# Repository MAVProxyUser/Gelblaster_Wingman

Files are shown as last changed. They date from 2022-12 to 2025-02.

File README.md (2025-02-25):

# Gelblaster Wingman Robotic Sentry Turret

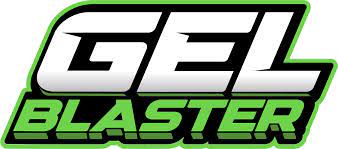
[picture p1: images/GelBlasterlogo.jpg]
Gelblasters (https://gelblaster.com)


Direct link to Bambu Labs printer files<br>
https://makerworld.com/en/models/787554#profileId-725499<br>
https://makerworld.com/en/models/787567#profileId-725512<br>

If you are interested in building & programming your own "Wingman" turret stop by:<br>
https://join.slack.com/t/robotdogs/shared_invite/zt-24ep8mqn4-1p42Aq7owRv9klLI~3C5Pw and join #gelblasters 

* [Gelblaster Wingman Robotic Sentry Turret](#gelblaster-wingman-robotic-sentry-turret)
   * [Synopsis](#synopsis)
   * [December 2024 - First Outdoor Test](#december-2024---first-outdoor-test)
   * [Introduction](#introduction)
   * [Licensing](#licensing)
   * [Build Steps](#build-steps)
      * [Required parts](#required-parts)
      * [Printing](#printing)
   * [Making a sentry gun](#making-a-sentry-gun)
      * [Required plumbing](#required-plumbing)
      * [Transplant of GelBlaster XL electronics](#transplant-of-gelblaster-xl-electronics)
      * [More 3d printing](#more-3d-printing)
      * [Recommended additional parts](#recommended-additional-parts)
         * [Motion Control](#motion-control)
         * [Computing](#computing)
         * [Power System](#power-system)

## Synopsis 

Ever since we saw James Cameron's "Aliens" in 1986, and Frank Marshall's "Congo" in 1995 we knew we needed to own an automated sentry turret at some point in our lifetime. It wasn't clear we'd eventually be sharing the design to one for others to use, but here we sit, doing exactly that. 

"Wingman" is a  licensed Open Source "GelBlaster" turret for ["general-purpose robots"](https://www.bostondynamics.com/open-letter-opposing-weaponization-general-purpose-robots). "Wingman" is designed with gamification of non-lethal adversarial Gelblaster sparring matches in mind. It makes robot assisted marksmanship a key compnent of playtime, are you ready to fight your robot overlords? No!? Well, you better get to training sooner than later!

liquor pour (https://www.youtube.com/watch?v=IS2PtmM9mwU) 

## December 2024 - First Outdoor Test
Latest Status Dec 2024 (https://youtube.com/shorts/UjThLahqY9g)<br>

## Current Tracking Response
Current Tracking Response (https://youtube.com/shorts/NoIiMvJtIzc?si=dIlFipVr6tI9Dh-7)<br>

## Introduction

[Gelblaster](https://gelblaster.com) XL "Wingman" is a robotic turret, that shoots gel balls aka Gellets(tm) at targets as selected by AI logic. The Gelblaster based "Wingman turret SDK" was inspired by U.S. Army [TARDEC](https://asc.army.mil/web/news-alt-jfm18-wingman-is-first-step-toward-weaponized-robotics/) - Tank-automotive and Armaments Command, [Open Robotics](https://www.openrobotics.org) [ROS-M](https://rosmilitary.org/faq/) military fork of Robot Operation System from GVSC - Combat Capabilities Development Command Ground Vehicle Systems Center, and their ["Wingman Robotic Gunner"](https://apps.dtic.mil/sti/pdfs/AD1069401.pdf) platform. Functionality of this project seeks to mimic concepts found in the [RTK](https://vimeo.com/593277076?) - Robotic Technology Kernel program. 

A gamified version of the "Wingman" concept known as [BloodHounds](https://github.com/MAVProxyUser/BloodHounds) is being designed by Kevin Finisterre for use with Quadruped robot dogs. This project is being tested, & developed with assistence from John Cherbini & the Gelblaster design team, as a means to visualize the "game". 

The design concept was pitched to the GelBlaster team, and the initial ideation phase reulted in the following proof of concept work. Thanks again to [GlytchTech](https://twitter.com/GlytchTech) for the very early prototypes, pre Gelblaster pitch.<br> 
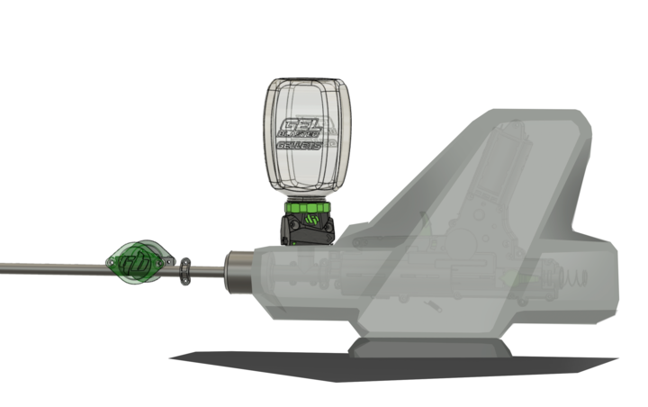
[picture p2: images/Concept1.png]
Concept1

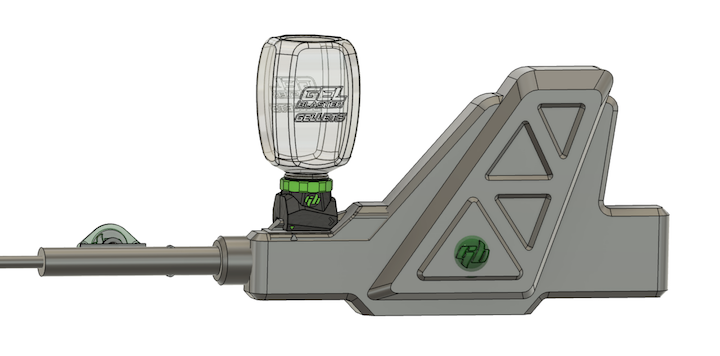
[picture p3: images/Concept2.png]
Concept2


The barrel seemed a bit vulnerable so we asked for a shroud.<br> 
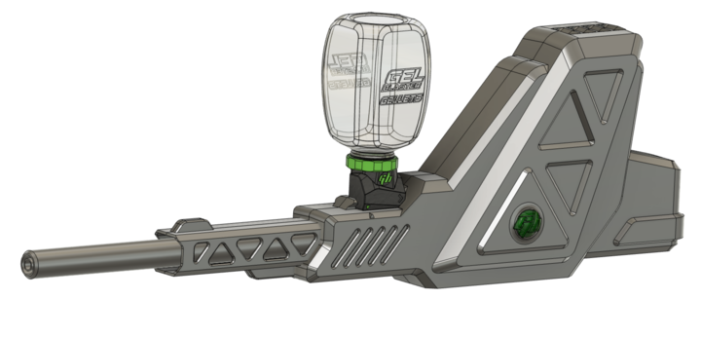
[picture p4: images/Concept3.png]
Concept3

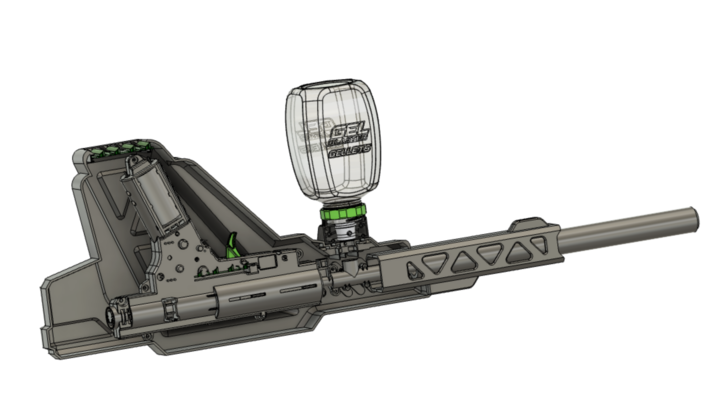
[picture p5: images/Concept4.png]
Concept4


We also needed a mounting system, pic rail seemed reasonable.<br> 
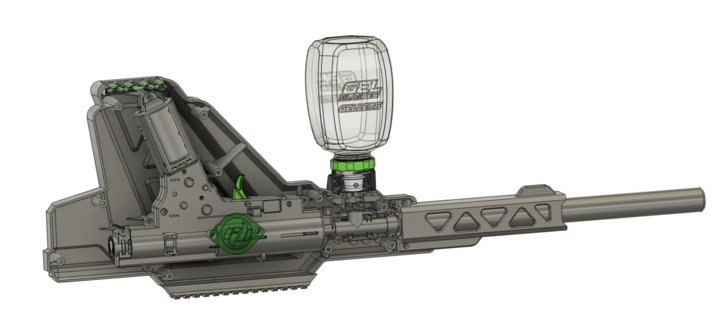
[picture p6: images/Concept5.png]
Concept5

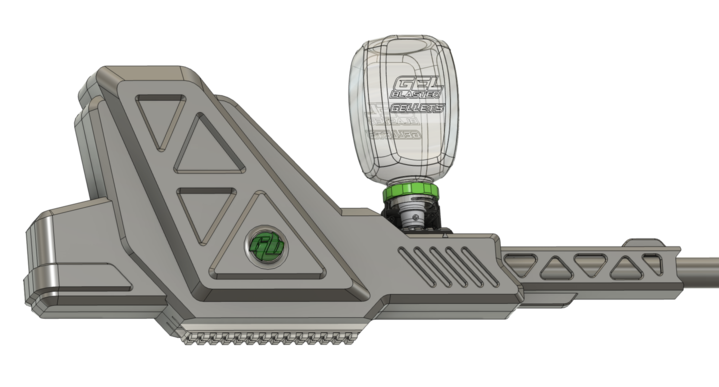
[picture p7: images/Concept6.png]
Concept6


Considerations over printability came next... and now we have something we can share. Mind you we still don't use the shroud, and we're testing sawed off barel designs. In otherwords, don't mind our mess while we are under construction.

## Licensing 

Creative Commons + Attribution-NonCommercial-ShareAlike licensing ( 
CC BY-NC-SA ) applies to the 3D files shared along side this text. This license lets others remix, adapt, and build upon your work non-commercially, as long as they credit you and license their new creations under the identical terms.

https://creativecommons.org/licenses/by-nc-sa/4.0/<br>
https://creativecommons.org/licenses/by-nc-sa/4.0/legalcode<br>

Under the following terms:

Attribution — You must give appropriate credit, provide a link to the license, and indicate if changes were made. You may do so in any reasonable manner, but not in any way that suggests the licensor endorses you or your use.

NonCommercial — You may not use the material for commercial purposes.

ShareAlike — If you remix, transform, or build upon the material, you must distribute your contributions under the same license as the original.

No additional restrictions — You may not apply legal terms or technological measures that legally restrict others from doing anything the license permits.

## Build Steps

### Required parts

[GelBlaster Surge XL](https://gelblaster.com/products/surge-xl)
or
[GelBlaster Starfire XL](https://gelblaster.com/products/starfire-xl). Either blaster can be purchased from [Walmart](https://www.walmart.com/ip/Gel-Blaster-Surge-XL-Day-N-Nite-Gel-Bead-Blaster-with-Glow-in-the-Dark-Starfire-Activator-5k-Starfire-Gellets-10k-Green-Gellets/1283028596), and [Target](https://www.target.com/p/gel-blaster-starfire-xl-glow-in-the-dark-gellet-blaster/-/A-86669382) respectively. 

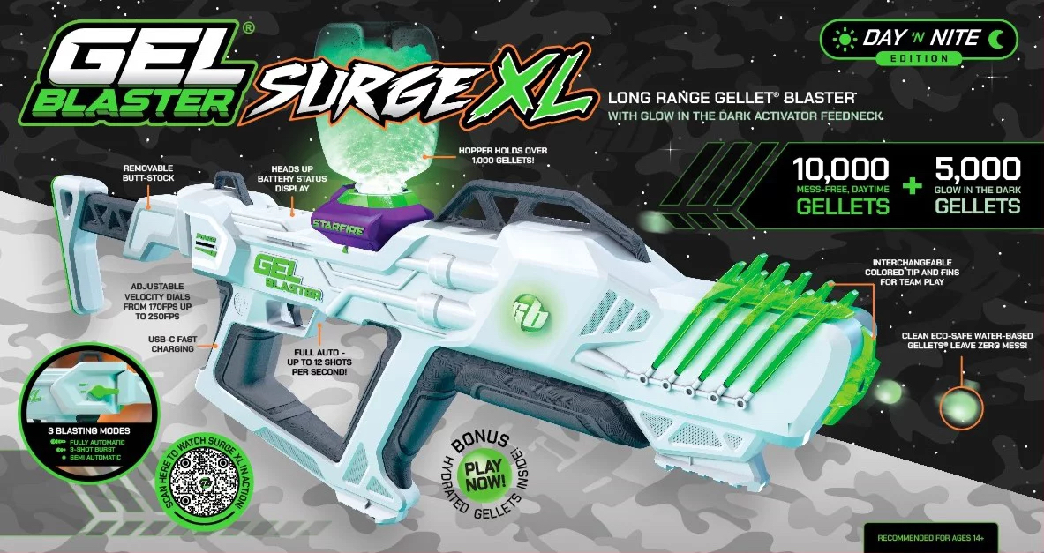
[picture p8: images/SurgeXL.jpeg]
SurgeXL

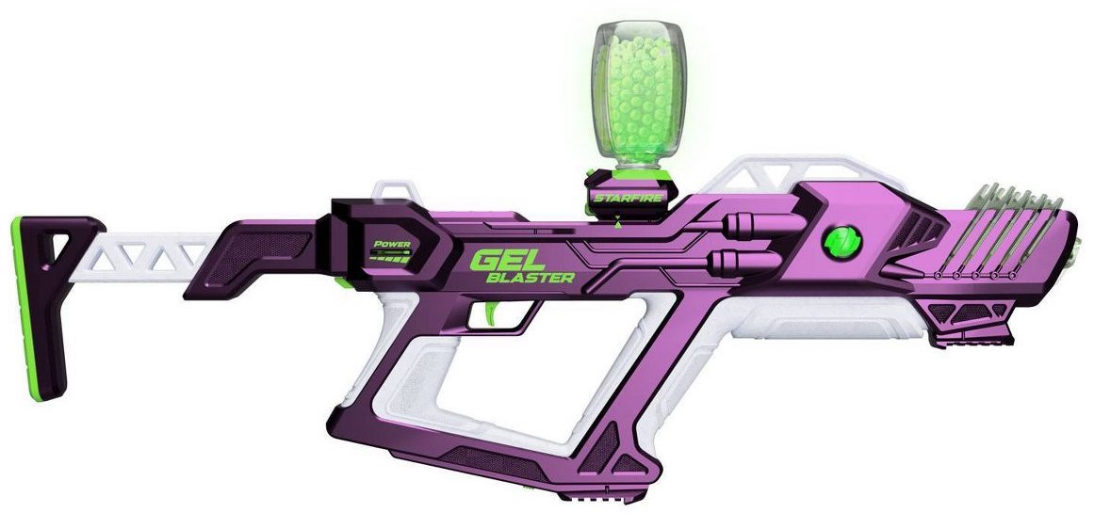
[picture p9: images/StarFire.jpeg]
StarFire XL


### Printing
The Wingman turret shell can be printed using the following pre-configured Bambu Lab build plates:

1. [Wingman GelBlaster Turret Case](https://makerworld.com/en/models/787567#profileId-725512)
2. [Wingman Turret Base](https://makerworld.com/en/models/787554#profileId-725499)

These build plates are optimized for the Bambu Lab A1 printer, but can be adapted for other printers. The complete print will take approximately 50 hours (6 hours for front pieces, 20 hours for each rear piece).

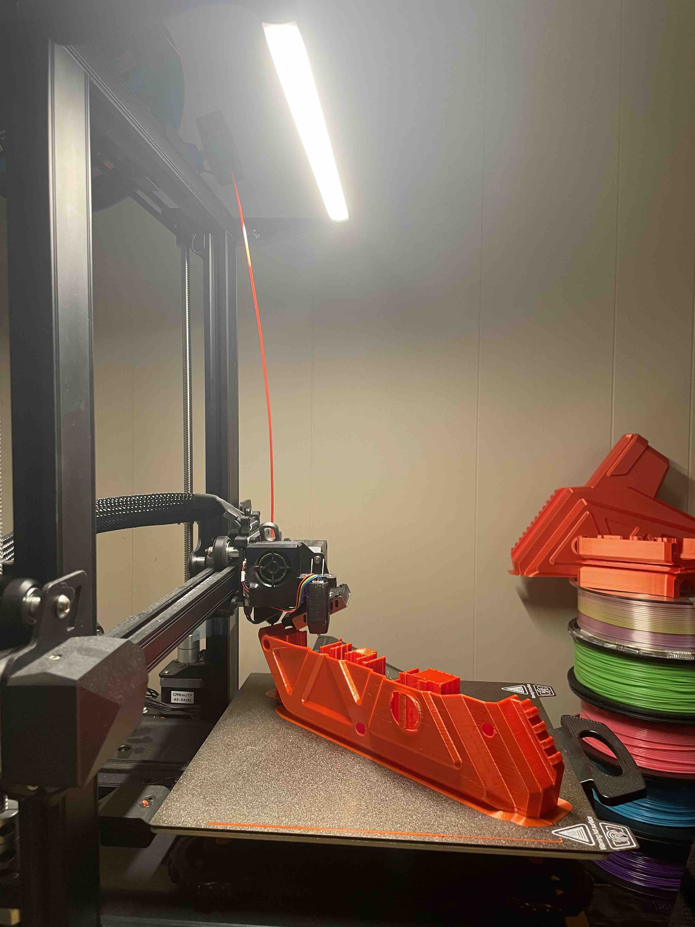
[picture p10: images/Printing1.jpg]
Printing1


After printing, you'll need to:
1. Remove support structures
2. Clean up the prints
3. Use Gorilla Glue (gel recommended) to join the shell pieces

For those wanting individual STL files:
[CC_BYNCSA_STL_Files directory](https://github.com/MAVProxyUser/Gelblaster_Wingman/)

## Making a sentry gun

### Required plumbing
First remove all the supporting screws in the GelBlaster XL shell, then remove the cosmetic shroud & barrel tip. Once the shell is open, remove the batery. <br>
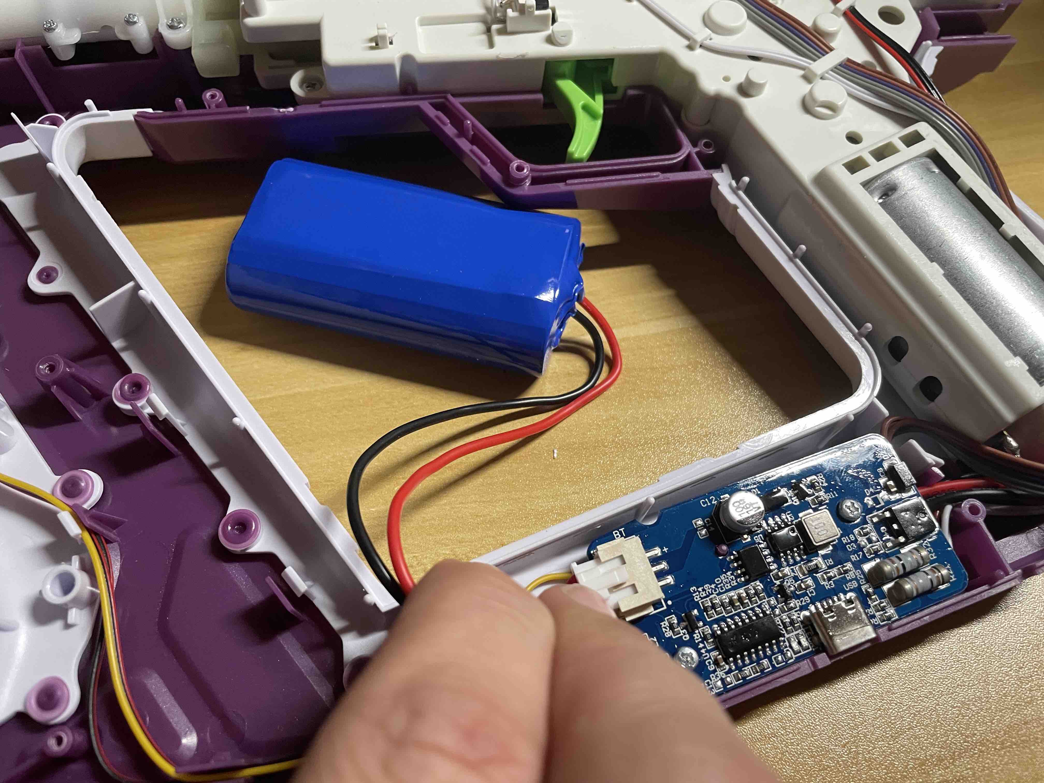
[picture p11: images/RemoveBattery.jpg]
RemoveBattery

Remove the screws and prepare to remove the gearbox.<br> 
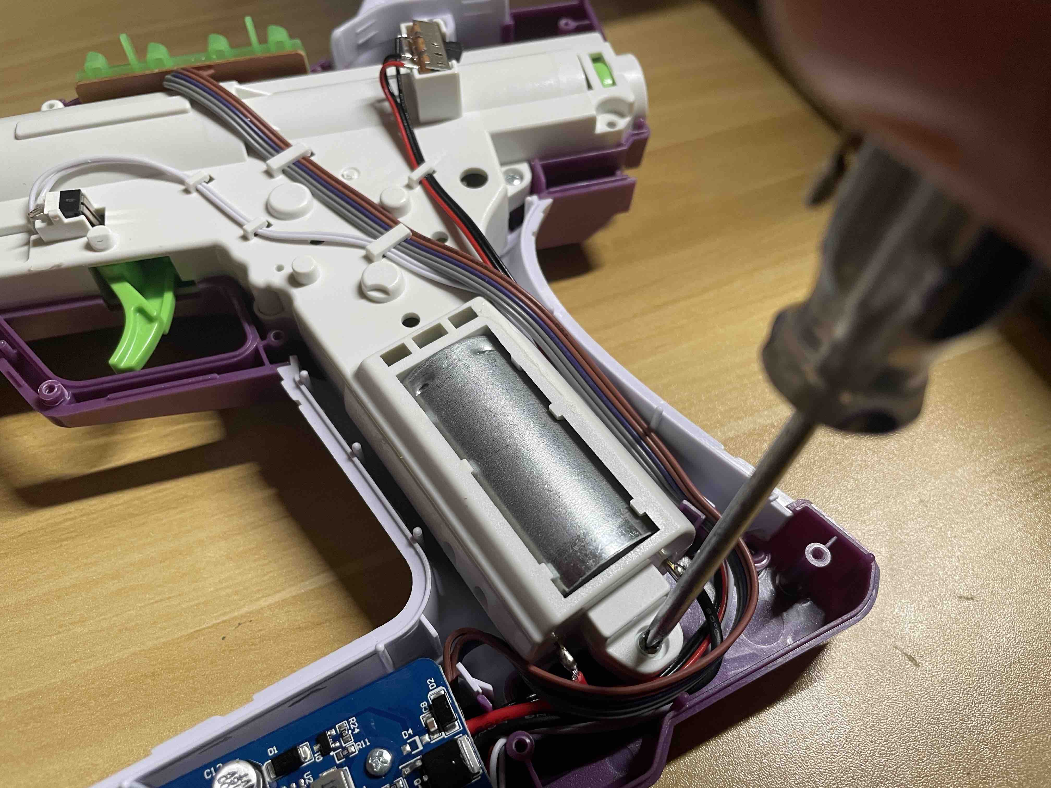
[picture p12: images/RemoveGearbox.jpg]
RemoveGearbox

Next remove the shim for the ammo hopper.<br> 
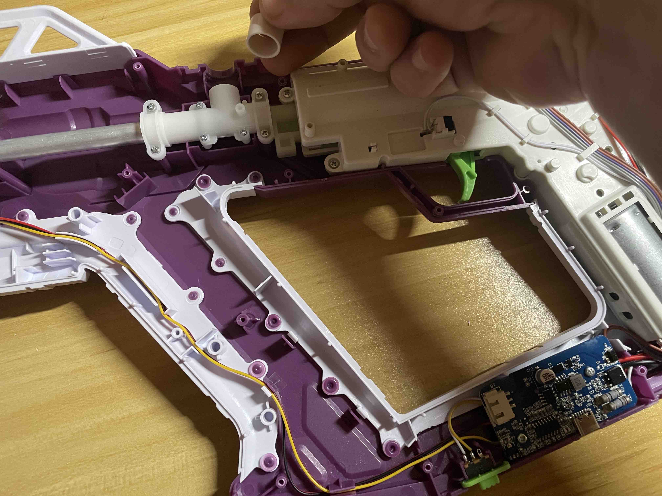
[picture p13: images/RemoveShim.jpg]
RemoveShim

Then remove the LED array, and associated cables. Do NOT disconnect them from the main PCB.<br> 
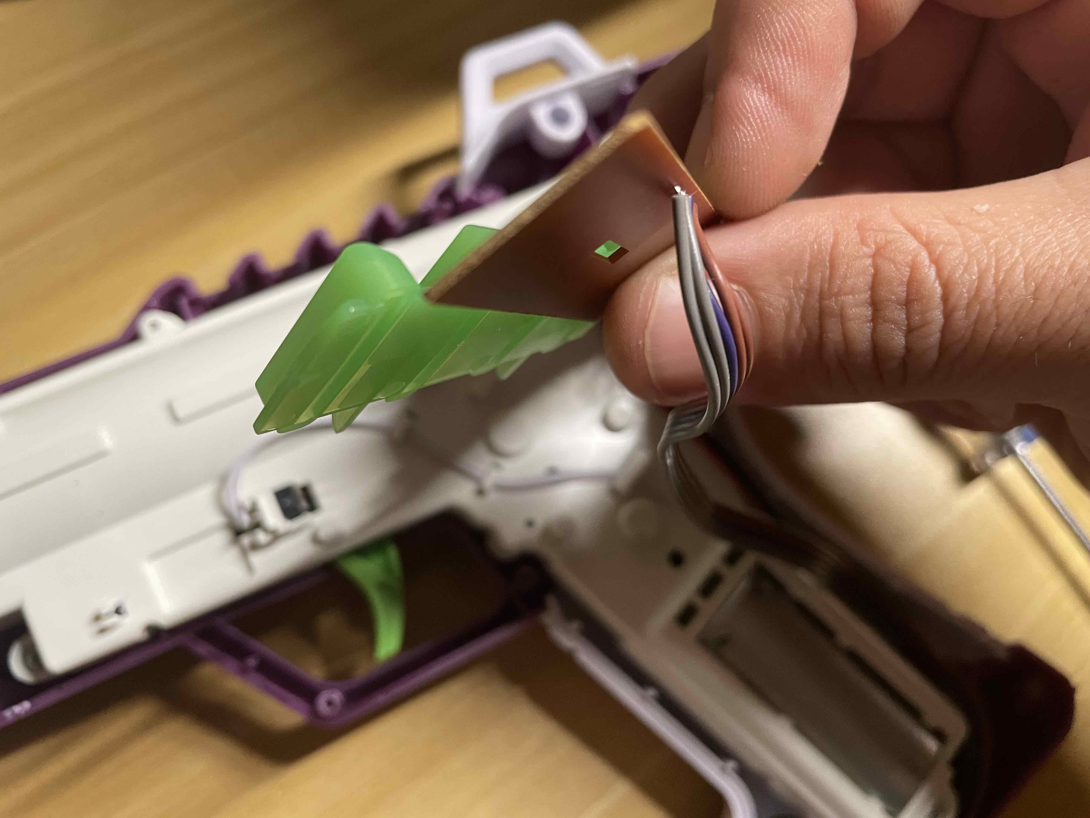
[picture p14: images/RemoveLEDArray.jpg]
RemoveLEDArray

Do the same with the other switches, and wires.<br> 
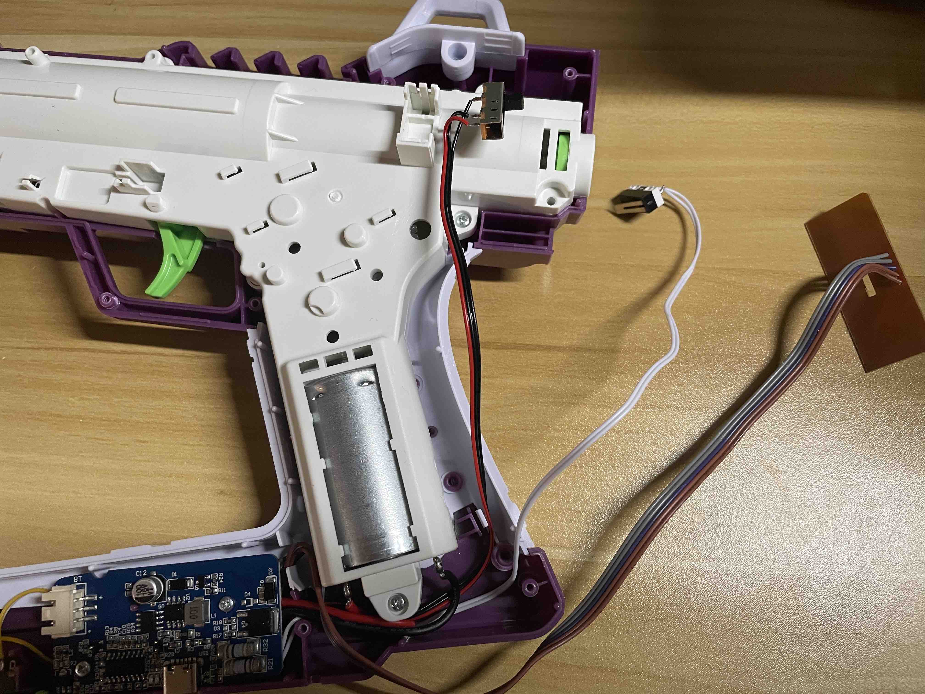
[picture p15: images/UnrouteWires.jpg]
UnrouteWires

Remove the screws holding down the PCB, and the barrel in place.<br> 
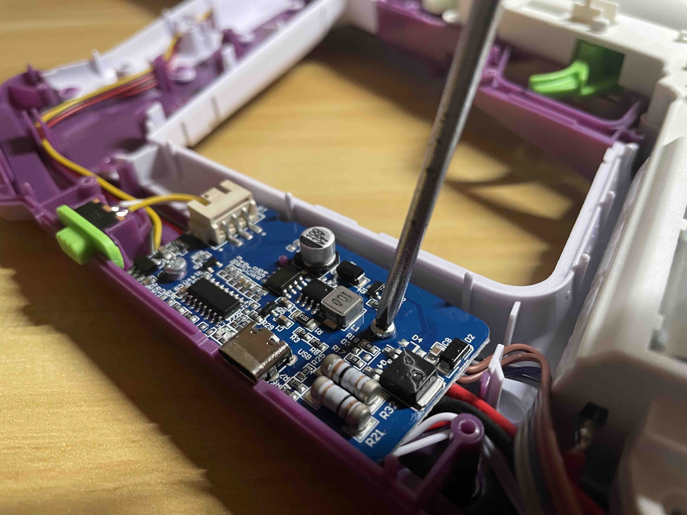
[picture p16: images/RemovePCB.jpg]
RemovePCB
 
Take the screws out of the barrel.<br>
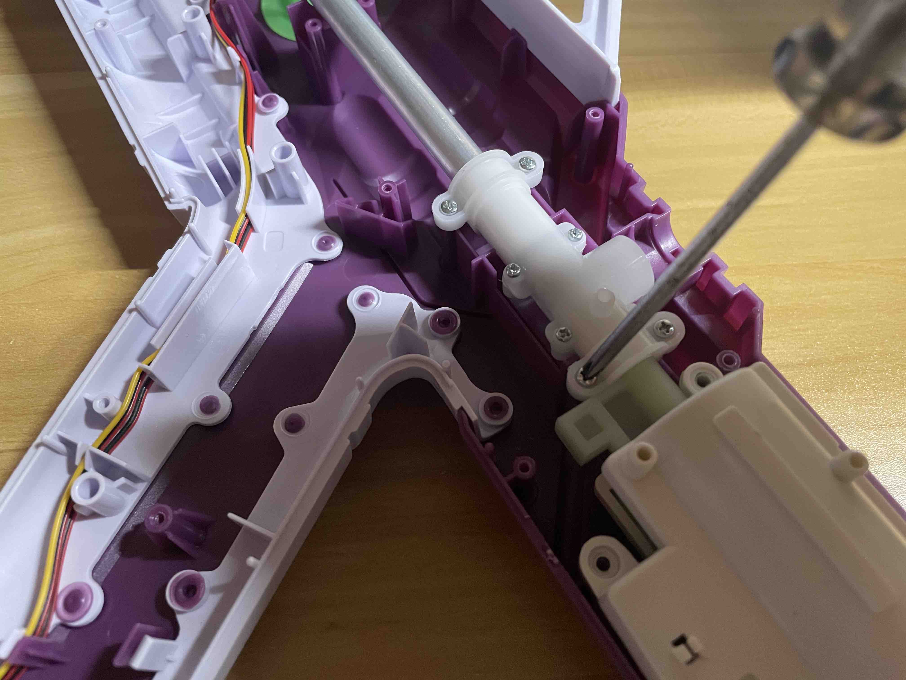
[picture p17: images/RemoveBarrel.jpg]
RemoveBarrel

Make sure to get the last few bits unscrewed.<br>
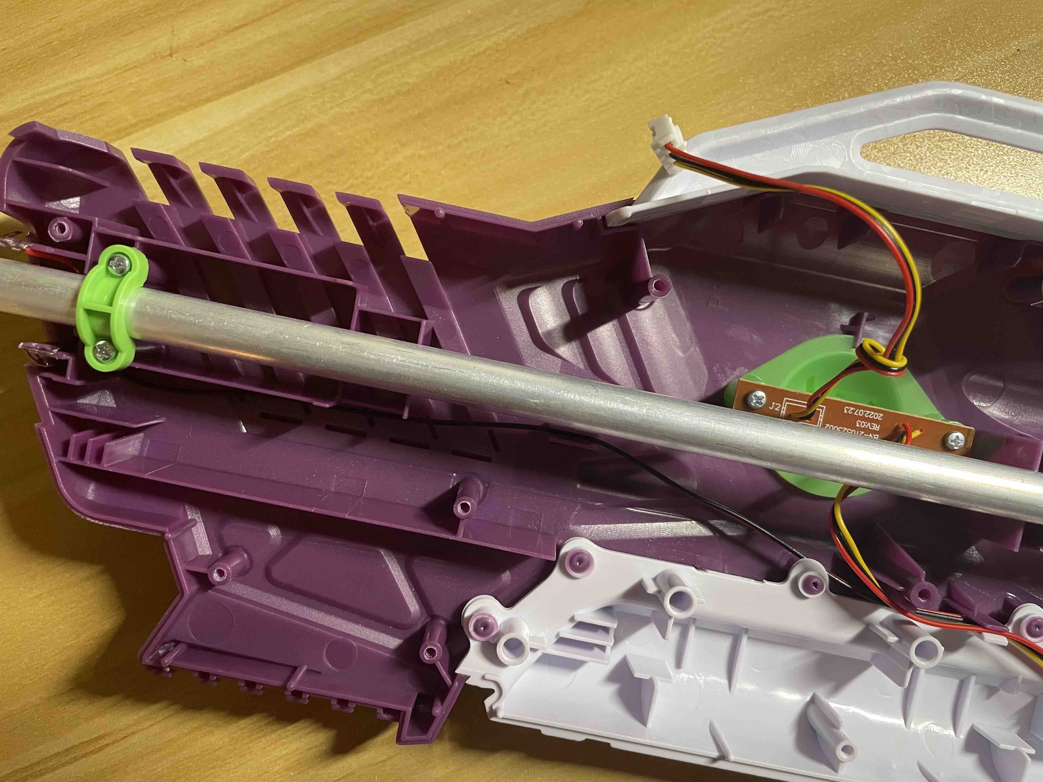
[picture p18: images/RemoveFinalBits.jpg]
RemoveFinalBits

Eventually you will have extracted the Gearbox in full.<br>
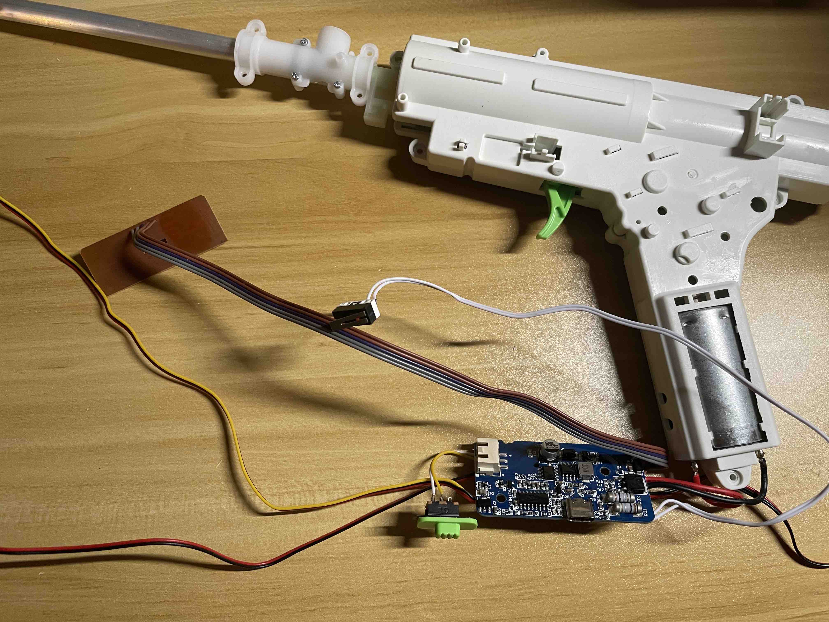
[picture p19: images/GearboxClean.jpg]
GearboxClean


### Transplant of GelBlaster XL electronics
Transplant all the parts to the shell (you will have some bits left over). Make sure to put the Logo & PCB in place before you start!<br> 
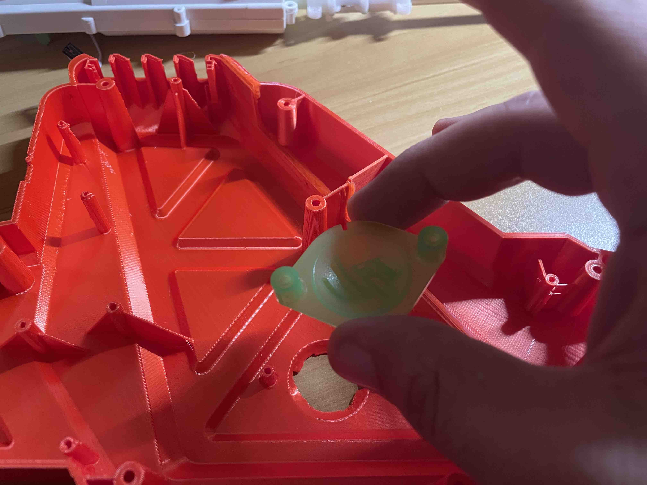
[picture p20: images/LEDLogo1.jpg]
LEDLogo1

Use all the screws you kept from the teardown. The logo LED's use two short screws, you should have four total.
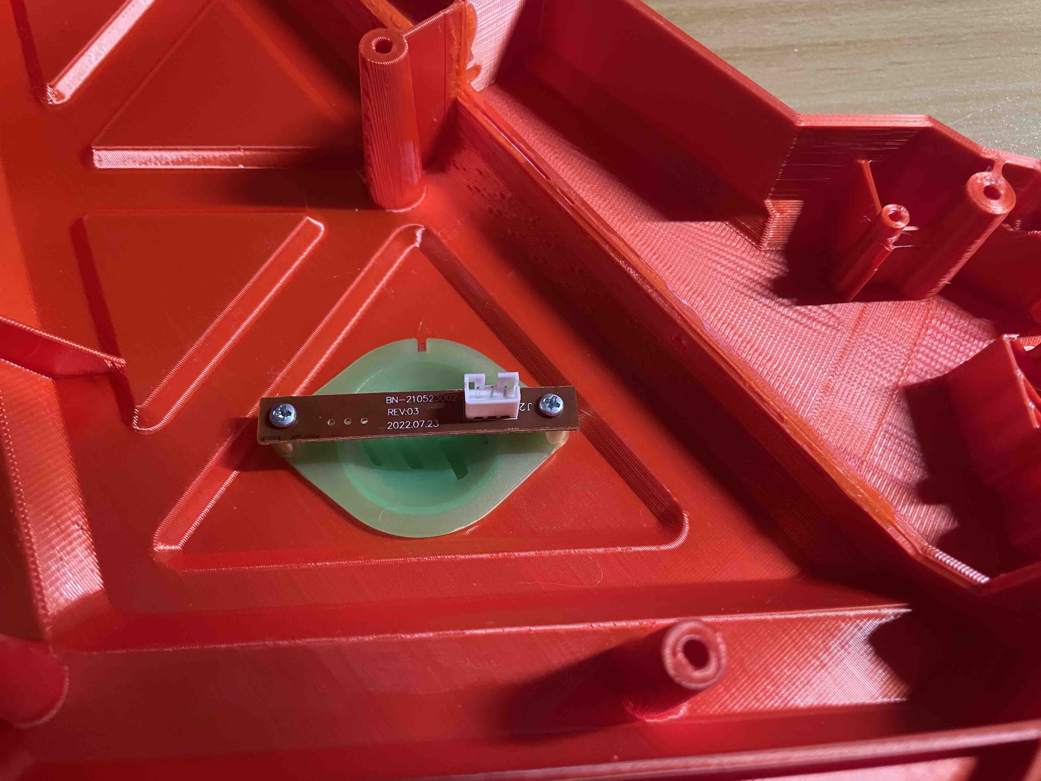
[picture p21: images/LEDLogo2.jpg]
LEDLogo2

Next start mounting the gearbox, and barrel. 

Connect the relay to the trigger

### More 3d printing
The turret base works fairly well, but there is always room for improvement. 

### Recommended additional parts

#### Motion Control
- [DYNAMIXEL XM430-W210](https://www.robotis.us/dynamixel-xm430-w210-t/) - Servo motor for turret movement
- [U2D2](https://www.robotis.us/u2d2/) - Dynamixel control board
- [U2D2 Power Hub](https://www.robotis.us/u2d2-power-hub-board-set/) - USB adapter for dynamixel
- Non-latching relay for trigger control

#### Computing
- [NVIDIA Jetson Xavier NX](https://www.nvidia.com/en-us/autonomous-machines/embedded-systems/jetson-xavier-nx/) - Main compute module
- 19V DC to DC Converter - Power regulation
- 5A inline fuse - Circuit protection

#### Power System
- [Li-Time 50AH LiFePo4 Battery](https://www.lithiumion-batteries.com/products/50ah-lifepo4-battery/) - Main power source
- Battery Charger - For LiFePo4 battery
- 4-gang rocker panel - Power distribution

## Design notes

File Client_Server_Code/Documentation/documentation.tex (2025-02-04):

\documentclass[12pt]{article}
\usepackage[a4paper,margin=1in]{geometry}
\usepackage{hyperref}
\usepackage{longtable}
\usepackage{array}
\usepackage{graphicx}
\usepackage{fancyhdr}
\usepackage{enumitem}

\setlength{\headheight}{14.5pt}  % Fix the header height warning

\pagestyle{fancy}
\fancyhf{}
\rhead{Turret System Documentation}
\lhead{GelBlaster - Wingman}
\rfoot{\thepage}

\title{Turret System Client--Server Application Documentation}
\author{GelBlaster - Wingman}
\date{February 2025}

\begin{document}
\maketitle
\tableofcontents
\newpage

\section{Introduction}

\subsection{Overview}
This documentation covers the client--server turret system application designed to provide remote control, camera feed handling, object detection, and hardware control (including servos and relay mechanisms) via MQTT communication. The system integrates software components with hardware (cameras, Dynamixel servos, GPIO, etc.) and provides both manual and automatic operational modes.

\subsection{Purpose and Scope}
\begin{itemize}[leftmargin=*, label={--}]
    \item \textbf{Purpose:} To document the design, architecture, installation, configuration, and usage of the turret system application. This documentation serves as a technical reference for developers, integrators, and maintainers.
    \item \textbf{Scope:} The document covers both the client and server code, explains the MQTT topics used for communication, details hardware requirements, and provides troubleshooting and future enhancement guidelines.
\end{itemize}

\subsection{Target Audience}
\begin{itemize}[leftmargin=*, label={--}]
    \item \textbf{Robotics Enthusiasts:} Makers and hobbyists interested in building automated turret systems or similar robotic projects
    \item \textbf{Software Developers:} Engineers working on computer vision, robotics control systems, or MQTT-based applications
    \item \textbf{Hardware Integrators:} Those working with Dynamixel servos, cameras, and GPIO systems
    \item \textbf{Gelblaster Community:} Users looking to enhance their Gelblaster XL with automated targeting capabilities
    \item \textbf{Venue Operators:} Gelblaster arena and entertainment venue operators interested in adding automated turret systems to their facilities
    \item \textbf{Academic/Research:} Students and researchers in robotics, computer vision, or human-robot interaction
\end{itemize}

\section{System Architecture}

\subsection{High-Level Overview}
The turret system is composed of two major parts:
\begin{description}
    \item[Client Application] Provides a graphical user interface (GUI) using OpenCV, processes incoming camera feed images, handles user inputs (keyboard and mouse), and sends control commands via MQTT.
    \item[Server Application] Interfaces with hardware components (camera, servos, relay), processes sensor data, detects objects (e.g., green objects), controls servo movements, and triggers the relay. It publishes the camera feed and status updates over MQTT.
\end{description}

\subsection{Client and Server Roles}
\textbf{Client:}
\begin{itemize}[leftmargin=*, label={--}]
    \item Receives live video feed from the server.
    \item Provides a control panel with manual override options (e.g., toggle auto/manual mode, adjust speed).
    \item Processes keyboard and mouse events to send directional commands.
    \item Publishes commands (e.g., pan/tilt adjustments, trigger commands) to MQTT topics.
\end{itemize}

\textbf{Server:}
\begin{itemize}[leftmargin=*, label={--}]
    \item Captures video frames using a connected camera (or an OAK-D device).
    \item Processes frames for object detection (e.g., identifying green objects).
    \item Reads and writes servo positions via Dynamixel controllers.
    \item Controls hardware relays (with GPIO) and publishes sensor/servo status.
    \item Subscribes to MQTT topics to receive command updates from the client.
\end{itemize}

\subsection{MQTT Communication and Topics}
The system uses the Paho MQTT library for messaging. Key topics include:
\begin{itemize}[leftmargin=*, label={--}]
    \item \textbf{Client-to-Server Topics:}
        \begin{itemize}[leftmargin=*, label={*}]
            \item \texttt{dpad/commands}: Contains directional commands, auto-mode toggles, and speed settings.
            \item \texttt{relay/command}: Commands for relay activation/deactivation.
            \item \texttt{server/sensitivity}: Commands to adjust sensitivity settings.
        \end{itemize}
    \item \textbf{Server-to-Client Topics:}
        \begin{itemize}[leftmargin=*, label={*}]
            \item \texttt{camera/feed}: Encoded JPEG images from the camera.
            \item \texttt{camera/bbox}: Bounding box data for detected objects.
            \item \texttt{servo/status}: Current servo positions and status updates.
            \item \texttt{server/tof}: Time-of-flight sensor data (if applicable).
        \end{itemize}
\end{itemize}

\subsection{Hardware and Software Dependencies}
\textbf{Hardware:}
\begin{itemize}[leftmargin=*, label={--}]
    \item Camera (webcam or OAK-D device)
    \item Dynamixel Servos (Pan and Tilt)
    \item Relay (controlled via GPIO, e.g., on a Linux-based system)
    \item (Optional) Input devices (gamepad, keyboard)
\end{itemize}

\textbf{Software:}
\begin{itemize}[leftmargin=*, label={--}]
    \item Python 3.x
    \item OpenCV
    \item NumPy
    \item Paho MQTT
    \item Pygame
    \item Platform-specific libraries (e.g., Jetson.GPIO, depthai, dynamixel\_sdk)
    \item Additional dependencies as required by the hardware (e.g., serial, netifaces)
\end{itemize}

\section{Software Components}

\subsection{Client Application}
\begin{itemize}[leftmargin=*, label={--}]
    \item \textbf{User Interface:} An OpenCV window displays the camera feed alongside a control panel. The control panel contains an Auto/Manual mode toggle button, a speed slider with touch-friendly controls, and real-time MQTT connection status.
    \item \textbf{Camera Feed Handling:} The client subscribes to the \texttt{camera/feed} topic, decodes JPEG images, and overlays additional UI elements (such as crosshairs and bounding boxes).
    \item \textbf{User Input Handling:} Keyboard (e.g., arrow keys, spacebar, ESC) and mouse events are captured. These inputs are translated into MQTT commands for panning, tilting, and firing the relay.
    \item \textbf{MQTT Integration:} The client connects to the MQTT broker, subscribes to several topics, and publishes control messages. Callback functions (e.g., \texttt{on\_connect}, \texttt{on\_message}) handle connection events and incoming messages.
\end{itemize}

\subsection{Server Application}
\begin{itemize}[leftmargin=*, label={--}]
    \item \textbf{Hardware Initialization:} On startup, the server configures the camera (using depthai or OpenCV based on the platform), initializes the GPIO for relay control (Linux only), and detects and initializes Dynamixel servos using the Dynamixel SDK.
    \item \textbf{Camera Feed and Processing:} The server continuously captures frames from the camera, processes them (e.g., flips the image, applies object detection algorithms), and publishes the processed frames over MQTT.
    \item \textbf{Servo and Relay Control:} Servo positions are read and written using dedicated functions. Control loops adjust servo positions based on manual commands or automatic corrections derived from object detection. The relay is triggered with debounce logic to prevent rapid switching.
    \item \textbf{Green Object Detection:} The server uses OpenCV to detect green objects within the camera feed. When an object is detected, its bounding box is computed, and if conditions are met (e.g., auto mode enabled and crosshair alignment), the relay is triggered.
    \item \textbf{MQTT Integration:} The server subscribes to command topics and publishes status updates (e.g., \texttt{servo/status}, \texttt{server/tof}). It processes messages to update sensitivity settings and control servo movements.
\end{itemize}

\section{Installation and Configuration}

\subsection{System Requirements}
\begin{itemize}[leftmargin=*, label={--}]
    \item \textbf{Operating Systems:}
    \begin{itemize}[leftmargin=*, label={*}]
        \item \textbf{Linux:} Full hardware integration (GPIO, Dynamixel servos).
        \item \textbf{macOS:} Limited to simulation or basic webcam usage; certain libraries (e.g., Jetson.GPIO) are not applicable.
    \end{itemize}
    \item \textbf{Hardware Components:}
    \begin{itemize}[leftmargin=*, label={*}]
        \item Camera (USB webcam or OAK-D)
        \item Dynamixel servos (e.g., U2D2 controller)
        \item Relay connected to a GPIO pin (for Linux systems)
        \item (Optional) External input devices
    \end{itemize}
\end{itemize}

\subsection{Software Dependencies and Setup}
\begin{enumerate}[leftmargin=*, label=\arabic*.]
    \item \textbf{Python 3.x:} Ensure Python 3 is installed.
    \item \textbf{Required Libraries:} Install the necessary packages using pip:
    \begin{verbatim}
pip install opencv-python numpy paho-mqtt pygame netifaces
    \end{verbatim}
    Additional packages for hardware integration:
    \begin{itemize}[leftmargin=*, label={--}]
        \item On \textbf{Linux:}
        \begin{verbatim}
pip install depthai dynamixel_sdk Jetson.GPIO
        \end{verbatim}
        \item On \textbf{macOS:} Installation instructions may vary; ensure OpenCV is compiled with AVFoundation support if required.
    \end{itemize}
    \item \textbf{MQTT Broker:} Set up an MQTT broker (e.g., Mosquitto). Update the broker IP and port in the code as needed.
\end{enumerate}

\subsection{Hardware Setup and Wiring}
\begin{itemize}[leftmargin=*, label={--}]
    \item \textbf{Camera:} Connect the camera to the system and verify that it is recognized by the operating system.
    \item \textbf{Dynamixel Servos:} Connect the servos to the U2D2 controller. Ensure the correct wiring and that the servos' IDs match those in the code (e.g., \texttt{DXL1\_ID} for pan and \texttt{DXL2\_ID} for tilt).
    \item \textbf{Relay and GPIO:} For Linux systems, ensure the GPIO library (e.g., Jetson.GPIO) is correctly configured. The relay pin (e.g., \texttt{RELAY\_PIN = 7}) should be wired to the relay hardware.
\end{itemize}

\subsection{MQTT Broker Setup}
\begin{itemize}[leftmargin=*, label={--}]
    \item Install and run an MQTT broker such as Mosquitto.
    \item Update the MQTT topics and broker IP addresses in the code:
    \begin{itemize}[leftmargin=*, label={*}]
        \item \texttt{MQTT\_BROKER}
        \item \texttt{MQTT\_PORT}
        \item All topic names (e.g., \texttt{dpad/commands}, \texttt{camera/feed}, etc.)
    \end{itemize}
\end{itemize}

\section{Usage Instructions}

\subsection{Running the Client Application}
\begin{enumerate}[leftmargin=*, label=\arabic*.]
    \item \textbf{Start the Application:} Run the client script from the command line:
    \begin{verbatim}
python3 turret_client.py
    \end{verbatim}
    \item \textbf{User Interface:} An OpenCV window titled ``Turret Client'' appears with:
    \begin{itemize}[leftmargin=*, label={--}]
        \item The live camera feed.
        \item A control panel on the left with an Auto/Manual toggle and speed slider.
        \item A status message indicating the MQTT connection status.
    \end{itemize}
    \item \textbf{Controls:} 
    \begin{itemize}[leftmargin=*, label={--}]
        \item \textbf{Keyboard:} Arrow keys or \texttt{W}, \texttt{A}, \texttt{S}, \texttt{D} to adjust pan and tilt; Spacebar to trigger the relay (simulate firing); ESC to exit.
        \item \textbf{Mouse:} Click on the control panel to toggle modes or adjust speed.
    \end{itemize}
\end{enumerate}

\subsection{Running the Server Application}
\begin{enumerate}[leftmargin=*, label=\arabic*.]
    \item \textbf{Start the Application:} Run the server script from the command line:
    \begin{verbatim}
python3 turret_server.py
    \end{verbatim}
    \item \textbf{Hardware Initialization:} The server will attempt to initialize the camera, GPIO (for relay), and Dynamixel servos. Check the console logs for status messages.
    \item \textbf{Operation Modes:}
    \begin{itemize}[leftmargin=*, label={--}]
        \item \textbf{Manual Mode:} Direct commands from the client override servo positions.
        \item \textbf{Auto Mode:} The system automatically adjusts the turret based on object detection (green objects).
    \end{itemize}
    \item \textbf{MQTT and Status Updates:} The server publishes camera frames and servo status updates to MQTT topics periodically.
\end{enumerate}

\subsection{User Interface and Controls}
\begin{itemize}[leftmargin=*, label={--}]
    \item \textbf{Control Panel:} Provides a visual interface for toggling auto/manual mode, adjusting the speed setting with a slider, and displaying MQTT connection status.
    \item \textbf{Visual Overlays:} The client displays crosshairs and bounding boxes (when a green object is detected) on the camera feed.
\end{itemize}

\section{Code Structure and Key Functions}

\subsection{Client Code Overview}
\begin{itemize}[leftmargin=*, label={--}]
    \item \textbf{MQTT Callbacks:} 
    \begin{itemize}[leftmargin=*, label={*}]
        \item \texttt{on\_connect(client, userdata, flags, reasonCode, properties)}: Handles successful MQTT connection and subscribes to necessary topics.
        \item \texttt{on\_message(client, userdata, msg)}: Processes incoming messages (camera frames, servo status, etc.).
    \end{itemize}
    \item \textbf{Main Loop (\texttt{main\_loop}):} Handles display updates, input events, and publishes control commands.
    \item \textbf{Input Handling:} Functions such as \texttt{mouse\_callback} and key event handling in the main loop manage user interactions.
    \item \textbf{UI Rendering:} Functions like \texttt{draw\_control\_panel} and \texttt{draw\_crosshair} create the visual elements in the OpenCV window.
\end{itemize}

\subsection{Server Code Overview}
\begin{itemize}[leftmargin=*, label={--}]
    \item \textbf{Hardware Initialization:}
    \begin{itemize}[leftmargin=*, label={*}]
        \item \texttt{initialize\_camera()}: Sets up the camera feed.
        \item \texttt{find\_dynamixel\_port()} and \texttt{initialize\_servos()}: Detect and initialize Dynamixel servos.
        \item \texttt{initialize\_home\_position()}: Establishes a reference "home" position for the servos.
    \end{itemize}
    \item \textbf{Image Processing and Object Detection:}
    \begin{itemize}[leftmargin=*, label={*}]
        \item \texttt{camera\_feed\_thread()}: Captures and processes video frames, performs object detection, and publishes the processed image.
        \item \texttt{detect\_green\_objects(frame)}: Uses HSV thresholding to detect green objects and compute their bounding boxes.
    \end{itemize}
    \item \textbf{Servo and Relay Control:}
    \begin{itemize}[leftmargin=*, label={*}]
        \item \texttt{control\_servos()}: Continuously updates servo positions based on either manual inputs or automatic corrections.
        \item \texttt{write\_servo\_position(dxl\_id, position)}: Sends position commands to the servos with error handling and retries.
        \item \texttt{trigger\_relay()}: Activates the relay with debounce logic.
    \end{itemize}
\end{itemize}

\subsection{Threading and Concurrency}
Multiple threads are used for:
\begin{itemize}[leftmargin=*, label={--}]
    \item \textbf{Camera Feed Processing:} Capturing, processing, and publishing video frames.
    \item \textbf{Servo Control Loop:} Continuously reading sensor data and updating servo positions.
    \item \textbf{MQTT Communication:} Running the MQTT client loop in a background thread.
\end{itemize}
Synchronization is managed using locks (e.g., \texttt{frame\_lock}, \texttt{command\_lock}) to ensure thread-safe operations.

\section{Error Handling and Logging}

\subsection{Logging Configuration}
\begin{itemize}[leftmargin=*, label={--}]
    \item The code uses Python's built-in \texttt{logging} module for debug and informational messages as well as error reporting with stack traces.
    \item Logging levels (e.g., DEBUG, INFO, ERROR) are set to provide detailed feedback during operation.
\end{itemize}

\subsection{Exception and Error Handling}
\begin{itemize}[leftmargin=*, label={--}]
    \item \textbf{Try/Except Blocks:} Most functions include try/except blocks to catch exceptions, log errors, and allow the system to continue operating.
    \item \textbf{Retries:} Functions such as \texttt{write\_servo\_position} and \texttt{read\_servo\_position} implement retry mechanisms to handle transient communication failures.
\end{itemize}

\subsection{Troubleshooting Tips}
\begin{itemize}[leftmargin=*, label={--}]
    \item \textbf{MQTT Connection Issues:} Check that the broker IP and port are correctly configured and that the broker is running.
    \item \textbf{Camera Feed Problems:} Verify that the correct camera (or OAK-D device) is connected and accessible.
    \item \textbf{Servo Communication:} Ensure that the Dynamixel servos are properly wired to the U2D2 controller and that their IDs match those specified in the code.
    \item \textbf{GPIO and Relay:} For Linux systems, ensure that GPIO libraries (e.g., Jetson.GPIO) are correctly installed and that the relay wiring is correct.
\end{itemize}

\section{Future Enhancements and Known Limitations}

\subsection{Future Enhancements}
\begin{itemize}[leftmargin=*, label={--}]
    \item Additional sensor integration (e.g., depth sensors, TOF sensors).
    \item Improved UI/UX for the control panel.
    \item Enhanced error recovery and logging mechanisms.
    \item Integration with additional input devices (e.g., game controllers).
\end{itemize}

\subsection{Known Limitations}
\begin{itemize}[leftmargin=*, label={--}]
    \item Some hardware-specific features are only available on Linux.
    \item The camera initialization may require further adjustments based on device models.
    \item The current auto-mode sensitivity and correction parameters might need fine-tuning for different environments.
\end{itemize}

\section{Appendices}

\subsection{MQTT Topics and Payload Formats}
\begin{center}
\begin{tabular}{|l|l|l|p{3cm}|}
\hline
\textbf{Topic} & \textbf{Direction} & \textbf{Payload Format} & \textbf{Description} \\
\hline
\texttt{dpad/commands} & Client $\rightarrow$ Server & JSON (e.g., \verb|{"pan_delta": 5}|) & Directional commands \\
\hline
\texttt{relay/command} & Client $\rightarrow$ Server & String (e.g., \verb|"off"|) & Relay control \\
\hline
\texttt{camera/feed} & Server $\rightarrow$ Client & JPEG bytes & Camera feed \\
\hline
\texttt{camera/bbox} & Server $\rightarrow$ Client & JSON & Bounding boxes \\
\hline
\texttt{servo/status} & Server $\rightarrow$ Client & JSON & Servo positions \\
\hline
\texttt{server/tof} & Server $\rightarrow$ Client & JSON & ToF data \\
\hline
\texttt{server/sensitivity} & Both & JSON & Sensitivity \\
\hline
\end{tabular}
\end{center}

\subsection{Library Versions and Dependencies}
\begin{itemize}[leftmargin=*, label={--}]
    \item \textbf{Python:} 3.7 or higher
    \item \textbf{OpenCV:} 4.x
    \item \textbf{NumPy:} 1.18 or higher
    \item \textbf{Paho MQTT:} 1.5.x
    \item \textbf{Pygame:} 2.x
    \item \textbf{Additional Libraries:} Refer to the installation instructions above for a complete list.
\end{itemize}

\subsection{References and Resources}
\begin{itemize}[leftmargin=*, label={--}]
    \item \href{https://www.eclipse.org/paho/}{Paho MQTT Documentation}
    \item \href{https://docs.opencv.org/}{OpenCV Documentation}
    \item \href{https://emanual.robotis.com/docs/en/software/dynamixel/dynamixel_sdk/}{Dynamixel SDK Documentation}
    \item \href{https://docs.luxonis.com/}{DepthAI Documentation}
\end{itemize}

\section{Contact and Support}
For further assistance, bug reports, or feature requests, please contact:
\begin{itemize}[leftmargin=*, label={--}]
    \item \textbf{Email:} \texttt{support@yourcompany.com}
    \item \textbf{Git Repository:} \url{https://github.com/MAVProxyUser/Gelblaster_Wingman}
    \item \textbf{Issue Tracker:} \url{https://github.com/MAVProxyUser/Gelblaster_Wingman/issues}
\end{itemize}

\bigskip
\noindent\textit{End of Documentation}

\end{document}

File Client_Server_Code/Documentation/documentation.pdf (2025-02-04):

# Turret System Client–Server Application Documentation

### GelBlaster - Wingman

### February 2025

## Contents

1 Introduction | 3
2 System Architecture | 3
3 Software Components | 5
4 Installation and Configuration | 6
5 Usage Instructions | 7
6 Code Structure and Key Functions | 8
7 Error Handling and Logging | 9

GelBlaster - Wingman | Turret System Documentation
8 Future Enhancements and Known Limitations | 10
9 Appendices | 10
10 Contact and Support | 11

## 1 Introduction

### 1.1 Overview

This documentation covers the client–server turret system application designed to provide remote control, camera feed handling, object detection, and hardware control (including servos and relay mechanisms) via MQTT communication. The system integrates software components with hardware (cameras, Dynamixel servos, GPIO, etc.) and provides both manual and automatic operational modes.

### 1.2 Purpose and Scope

– Purpose: To document the design, architecture, installation, configuration, and usage of the turret system application. This documentation serves as a technical reference for developers, integrators, and maintainers.

– Scope: The document covers both the client and server code, explains the MQTT topics used for communication, details hardware requirements, and provides troubleshooting and future enhancement guidelines.

### 1.3 Target Audience

– Robotics Enthusiasts: Makers and hobbyists interested in building automated turret systems or similar robotic projects

– Software Developers: Engineers working on computer vision, robotics control systems, or MQTT-based applications

– Hardware Integrators: Those working with Dynamixel servos, cameras, and GPIO systems

– Gelblaster Community: Users looking to enhance their Gelblaster XL with automated targeting capabilities

– Venue Operators: Gelblaster arena and entertainment venue operators interested in adding automated turret systems to their facilities

– Academic/Research: Students and researchers in robotics, computer vision, or human-robot interaction

## 2 System Architecture

### 2.1 High-Level Overview

The turret system is composed of two major parts:

Client Application Provides a graphical user interface (GUI) using OpenCV, processes incoming camera feed images, handles user inputs (keyboard and mouse), and sends control commands via MQTT.

Server Application Interfaces with hardware components (camera, servos, relay), processes sensor data, detects objects (e.g., green objects), controls servo movements, and triggers the relay. It publishes the camera feed and status updates over MQTT.

### 2.2 Client and Server Roles

Client:

– Receives live video feed from the server.

– Provides a control panel with manual override options (e.g., toggle auto/manual mode, adjust speed).

– Processes keyboard and mouse events to send directional commands.

– Publishes commands (e.g., pan/tilt adjustments, trigger commands) to MQTT topics.

Server:

– Captures video frames using a connected camera (or an OAK-D device).

– Processes frames for object detection (e.g., identifying green objects).

– Reads and writes servo positions via Dynamixel controllers.

– Controls hardware relays (with GPIO) and publishes sensor/servo status.

– Subscribes to MQTT topics to receive command updates from the client.

### 2.3 MQTT Communication and Topics

The system uses the Paho MQTT library for messaging. Key topics include:

– Client-to-Server Topics:

* dpad/commands: Contains directional commands, auto-mode toggles, and speed settings.

* relay/command: Commands for relay activation/deactivation.

* server/sensitivity: Commands to adjust sensitivity settings.

– Server-to-Client Topics:

* camera/feed: Encoded JPEG images from the camera.

* camera/bbox: Bounding box data for detected objects.

* servo/status: Current servo positions and status updates.

* server/tof: Time-of-flight sensor data (if applicable).

### 2.4 Hardware and Software Dependencies

Hardware:

– Camera (webcam or OAK-D device)

– Dynamixel Servos (Pan and Tilt)

– Relay (controlled via GPIO, e.g., on a Linux-based system)

– (Optional) Input devices (gamepad, keyboard)

Software:

– Python 3.x

– OpenCV

– NumPy

– Paho MQTT

– Pygame

– Platform-specific libraries (e.g., Jetson.GPIO, depthai, dynamixel sdk)

– Additional dependencies as required by the hardware (e.g., serial, netifaces)

## 3 Software Components

### 3.1 Client Application

– User Interface: An OpenCV window displays the camera feed alongside a control panel. The control panel contains an Auto/Manual mode toggle button, a speed slider with touch-friendly controls, and real-time MQTT connection status.

– Camera Feed Handling: The client subscribes to the camera/feed topic, decodes JPEG images, and overlays additional UI elements (such as crosshairs and bounding boxes).

– User Input Handling: Keyboard (e.g., arrow keys, spacebar, ESC) and mouse events are captured. These inputs are translated into MQTT commands for panning, tilting, and firing the relay.

– MQTT Integration: The client connects to the MQTT broker, subscribes to several topics, and publishes control messages. Callback functions (e.g., on connect, on message) handle connection events and incoming messages.

### 3.2 Server Application

– Hardware Initialization: On startup, the server configures the camera (using depthai or OpenCV based on the platform), initializes the GPIO for relay control (Linux only), and detects and initializes Dynamixel servos using the Dynamixel SDK.

– Camera Feed and Processing: The server continuously captures frames from the camera, processes them (e.g., flips the image, applies object detection algorithms), and publishes the processed frames over MQTT.

– Servo and Relay Control: Servo positions are read and written using dedicated functions. Control loops adjust servo positions based on manual commands or automatic corrections derived from object detection. The relay is triggered with debounce logic to prevent rapid switching.

– Green Object Detection: The server uses OpenCV to detect green objects within the camera feed. When an object is detected, its bounding box is computed, and if conditions are met (e.g., auto mode enabled and crosshair alignment), the relay is triggered.

– MQTT Integration: The server subscribes to command topics and publishes status updates (e.g., servo/status, server/tof). It processes messages to update sensitivity settings and control servo movements.

## 4 Installation and Configuration

### 4.1 System Requirements

– Operating Systems:

* Linux: Full hardware integration (GPIO, Dynamixel servos).

* macOS: Limited to simulation or basic webcam usage; certain libraries (e.g., Jetson.GPIO) are not applicable.

– Hardware Components:

* Camera (USB webcam or OAK-D)

* Dynamixel servos (e.g., U2D2 controller)

* Relay connected to a GPIO pin (for Linux systems)

* (Optional) External input devices

### 4.2 Software Dependencies and Setup

1. Python 3.x: Ensure Python 3 is installed.
2. Required Libraries: Install the necessary packages using pip:

pip install opencv-python numpy paho-mqtt pygame netifaces

Additional packages for hardware integration:

– On Linux:

pip install depthai dynamixel_sdk Jetson.GPIO

– On macOS: Installation instructions may vary; ensure OpenCV is compiled with AVFoundation support if required.

3. MQTT Broker: Set up an MQTT broker (e.g., Mosquitto). Update the broker IP and port in the code as needed.

### 4.3 Hardware Setup and Wiring

– Camera: Connect the camera to the system and verify that it is recognized by the operating system.

– Dynamixel Servos: Connect the servos to the U2D2 controller. Ensure the correct wiring and that the servos’ IDs match those in the code (e.g., DXL1 ID for pan and DXL2 ID for tilt).

– Relay and GPIO: For Linux systems, ensure the GPIO library (e.g., Jetson.GPIO) is correctly configured. The relay pin (e.g., RELAY PIN = 7) should be wired to the relay hardware.

### 4.4 MQTT Broker Setup

– Install and run an MQTT broker such as Mosquitto.

– Update the MQTT topics and broker IP addresses in the code:

* MQTT BROKER

* MQTT PORT

* All topic names (e.g., dpad/commands, camera/feed, etc.)

## 5 Usage Instructions

### 5.1 Running the Client Application

1. Start the Application: Run the client script from the command line:

python3 turret_client.py

2. User Interface: An OpenCV window titled “Turret Client” appears with:

– The live camera feed.

– A control panel on the left with an Auto/Manual toggle and speed slider.

– A status message indicating the MQTT connection status.

3. Controls:

– Keyboard: Arrow keys or W, A, S, D to adjust pan and tilt; Spacebar to trigger the relay (simulate firing); ESC to exit.

– Mouse: Click on the control panel to toggle modes or adjust speed.

### 5.2 Running the Server Application

1. Start the Application: Run the server script from the command line:

python3 turret_server.py

2. Hardware Initialization: The server will attempt to initialize the camera, GPIO (for relay), and Dynamixel servos. Check the console logs for status messages.
3. Operation Modes:

– Manual Mode: Direct commands from the client override servo positions.
– Auto Mode: The system automatically adjusts the turret based on object detection (green objects).
4. MQTT and Status Updates: The server publishes camera frames and servo status updates to MQTT topics periodically.

### 5.3 User Interface and Controls

– Control Panel: Provides a visual interface for toggling auto/manual mode, adjusting the speed setting with a slider, and displaying MQTT connection status.

– Visual Overlays: The client displays crosshairs and bounding boxes (when a green object is detected) on the camera feed.

## 6 Code Structure and Key Functions

### 6.1 Client Code Overview

– MQTT Callbacks:

* on connect(client, userdata, flags, reasonCode, properties): Handles successful MQTT connection and subscribes to necessary topics.
* on message(client, userdata, msg): Processes incoming messages (camera frames, servo status, etc.).

– Main Loop (main loop): Handles display updates, input events, and publishes control commands.

– Input Handling: Functions such as mouse callback and key event handling in the main loop manage user interactions.

– UI Rendering: Functions like draw control panel and draw crosshair create the visual elements in the OpenCV window.

### 6.2 Server Code Overview

– Hardware Initialization:

* initialize camera(): Sets up the camera feed.

* find dynamixel port() and initialize servos(): Detect and initialize Dynamixel servos.

* initialize home position(): Establishes a reference ”home” position for the servos.

– Image Processing and Object Detection:

* camera feed thread(): Captures and processes video frames, performs object detection, and publishes the processed image.

* detect green objects(frame): Uses HSV thresholding to detect green objects and compute their bounding boxes.

– Servo and Relay Control:

* control servos(): Continuously updates servo positions based on either manual inputs or automatic corrections.

* write servo position(dxl id, position): Sends position commands to the servos with error handling and retries.

* trigger relay(): Activates the relay with debounce logic.

### 6.3 Threading and Concurrency

Multiple threads are used for:

– Camera Feed Processing: Capturing, processing, and publishing video frames.

– Servo Control Loop: Continuously reading sensor data and updating servo positions.

– MQTT Communication: Running the MQTT client loop in a background thread.

Synchronization is managed using locks (e.g., frame lock, command lock) to ensure thread-safe operations.

## 7 Error Handling and Logging

### 7.1 Logging Configuration

– The code uses Python’s built-in logging module for debug and informational messages as well as error reporting with stack traces.

– Logging levels (e.g., DEBUG, INFO, ERROR) are set to provide detailed feedback during operation.

### 7.2 Exception and Error Handling

– Try/Except Blocks: Most functions include try/except blocks to catch exceptions, log errors, and allow the system to continue operating.

– Retries: Functions such as write servo position and read servo position implement retry mechanisms to handle transient communication failures.

### 7.3 Troubleshooting Tips

– MQTT Connection Issues: Check that the broker IP and port are correctly configured and that the broker is running.

– Camera Feed Problems: Verify that the correct camera (or OAK-D device) is connected and accessible.

– Servo Communication: Ensure that the Dynamixel servos are properly wired to the U2D2 controller and that their IDs match those specified in the code.

– GPIO and Relay: For Linux systems, ensure that GPIO libraries (e.g., Jetson.GPIO) are correctly installed and that the relay wiring is correct.

## 8 Future Enhancements and Known Limitations

### 8.1 Future Enhancements

– Additional sensor integration (e.g., depth sensors, TOF sensors).

– Improved UI/UX for the control panel.

– Enhanced error recovery and logging mechanisms.

– Integration with additional input devices (e.g., game controllers).

### 8.2 Known Limitations

– Some hardware-specific features are only available on Linux.

– The camera initialization may require further adjustments based on device models.

– The current auto-mode sensitivity and correction parameters might need fine-tuning for different environments.

## 9 Appendices

### 9.1 MQTT Topics and Payload Formats

Topic | Direction | Payload Format | Description
dpad/commands | Client → Server | JSON (e.g., {"pan_delta": 5}) | Directional com-mands
relay/command | Client → Server | String (e.g., "off") | Relay control
camera/feed | Server → Client | JPEG bytes | Camera feed
camera/bbox | Server → Client | JSON | Bounding boxes
servo/status | Server → Client | JSON | Servo positions
server/tof | Server → Client | JSON | ToF data
server/sensitivity | Both | JSON | Sensitivity

### 9.2 Library Versions and Dependencies

– Python: 3.7 or higher

– OpenCV: 4.x

– NumPy: 1.18 or higher

– Paho MQTT: 1.5.x

– Pygame: 2.x

– Additional Libraries: Refer to the installation instructions above for a complete list.

### 9.3 References and Resources

– Paho MQTT Documentation (https://www.eclipse.org/paho/)

– OpenCV Documentation (https://docs.opencv.org/)

– Dynamixel SDK Documentation (https://emanual.robotis.com/docs/en/software/dynamixel/dynamixel_sdk/)

– DepthAI Documentation (https://docs.luxonis.com/)

## 10 Contact and Support

For further assistance, bug reports, or feature requests, please contact:

– Email: support@yourcompany.com

– Git Repository: https://github.com/MAVProxyUser/Gelblaster_Wingman

– Issue Tracker: https://github.com/MAVProxyUser/Gelblaster_Wingman/issues

End of Documentation

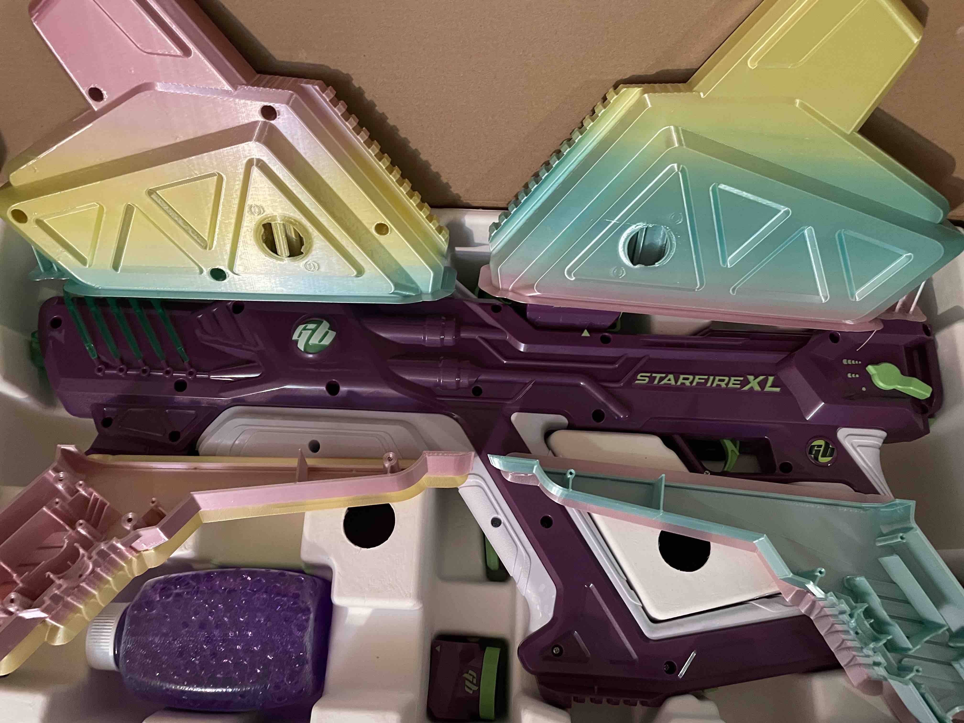
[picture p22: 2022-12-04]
images/Starfire1.jpeg

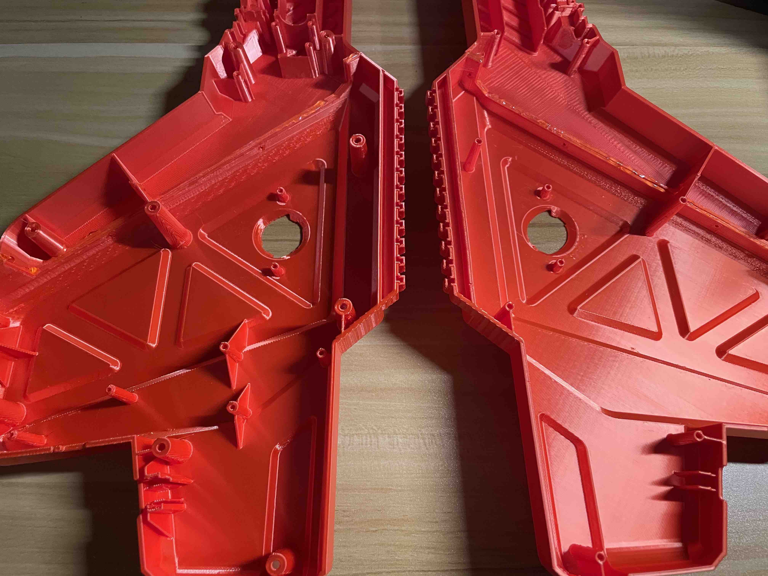
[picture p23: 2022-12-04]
images/SuperGlue4.jpeg

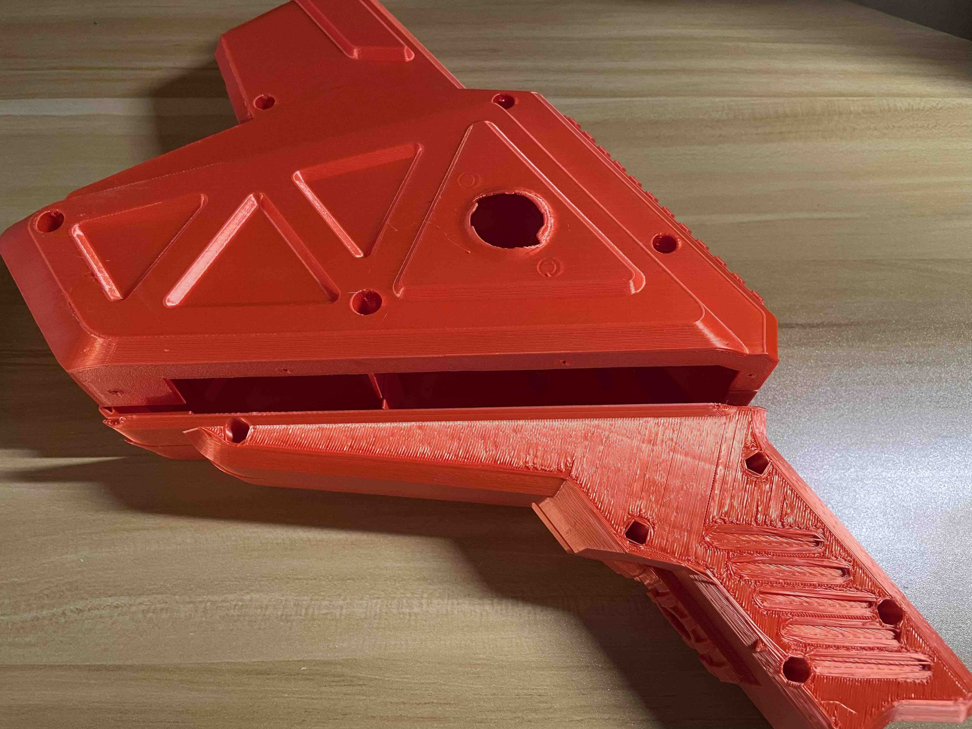
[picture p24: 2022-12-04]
images/Ready1.jpeg

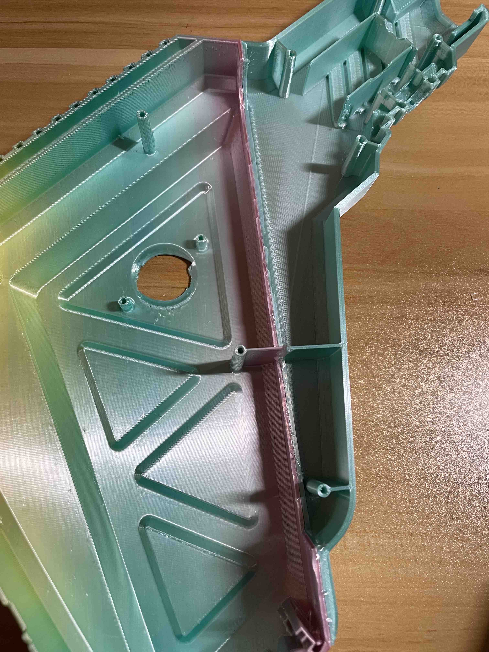
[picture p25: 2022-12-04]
images/SuperGlue2.jpeg

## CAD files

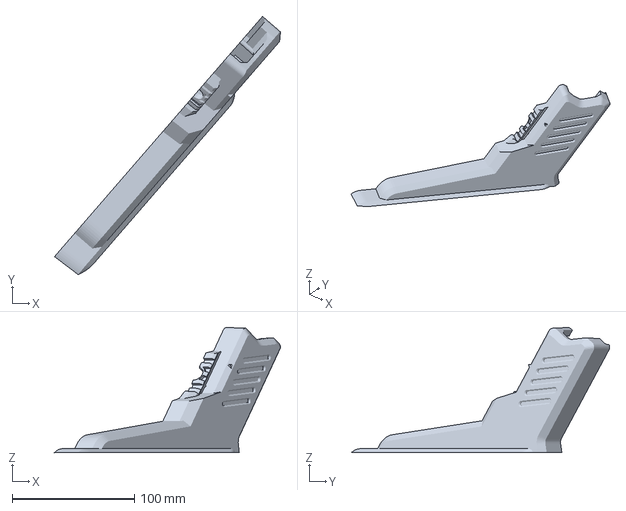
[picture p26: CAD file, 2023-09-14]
CC_BYNCSA_STL_Blaster/CC_BYNCSA_L_Front.3mf
184.7 x 211.1 x 102.2 mm

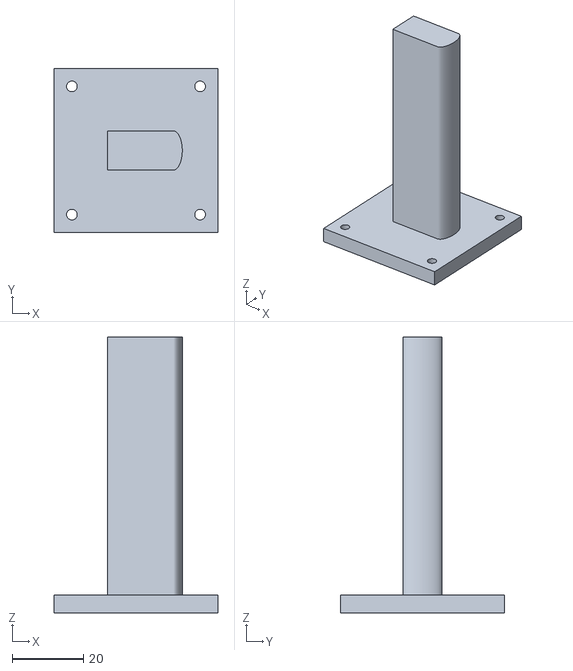
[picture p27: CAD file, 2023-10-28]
CC_BYNCSA_STL_Turret/JobyMount.stl
46.0 x 46.0 x 77.5

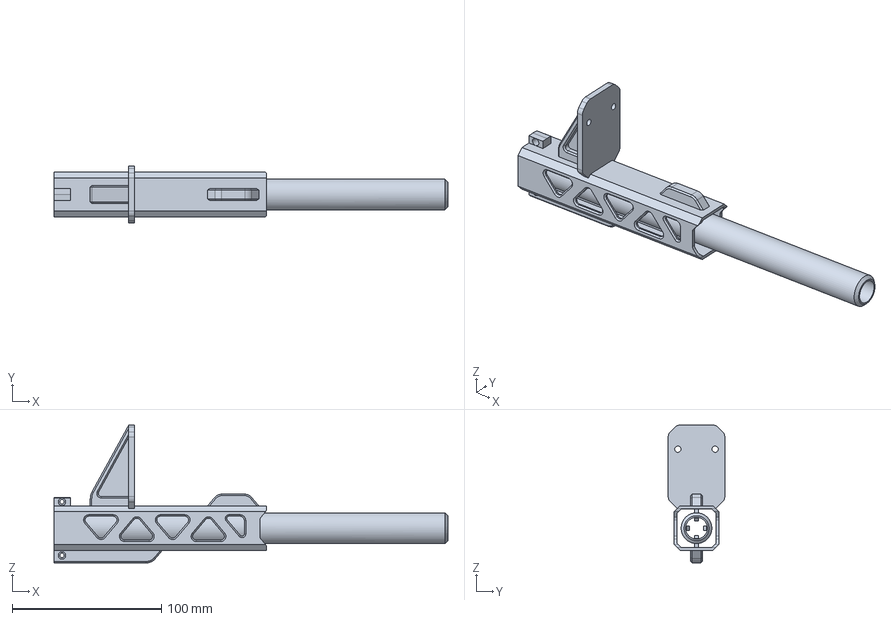
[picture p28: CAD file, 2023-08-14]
STEP/barrel.step
263.9 x 38.0 x 92.4 mm

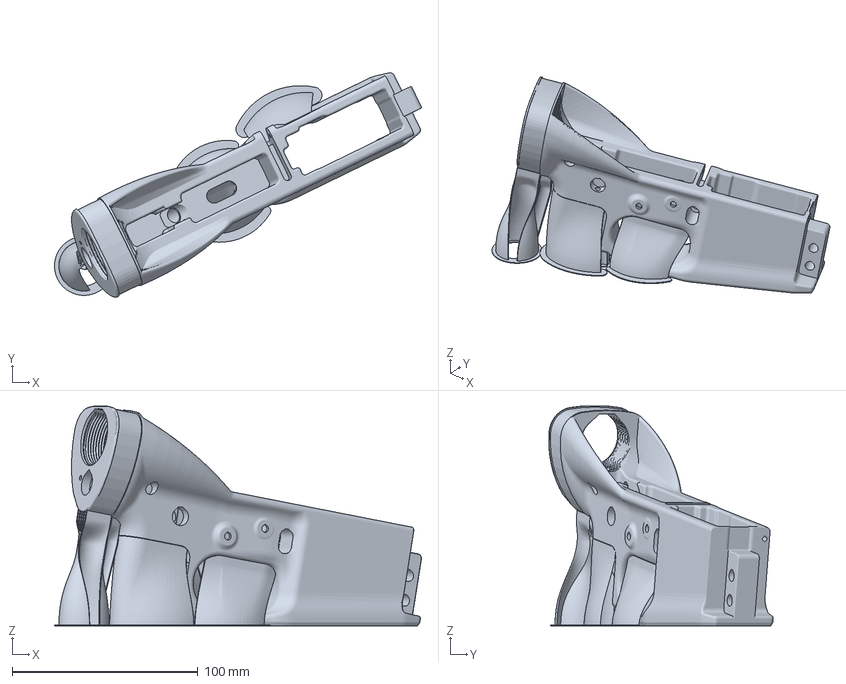
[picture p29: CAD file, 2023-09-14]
CC_BYNCSA_STL_Blaster/CC_BYNCSA_R_Back.3mf
197.6 x 120.9 x 118.2 mm

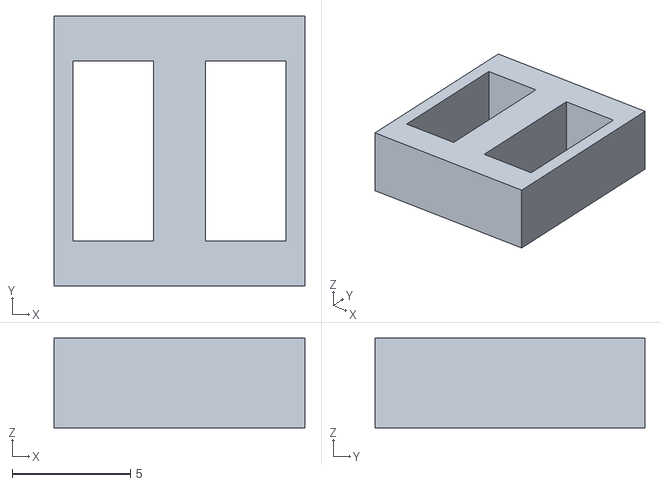
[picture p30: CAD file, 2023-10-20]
CC_BYNCSA_STL_Turret/buckle.stl
10.6 x 11.4 x 3.80

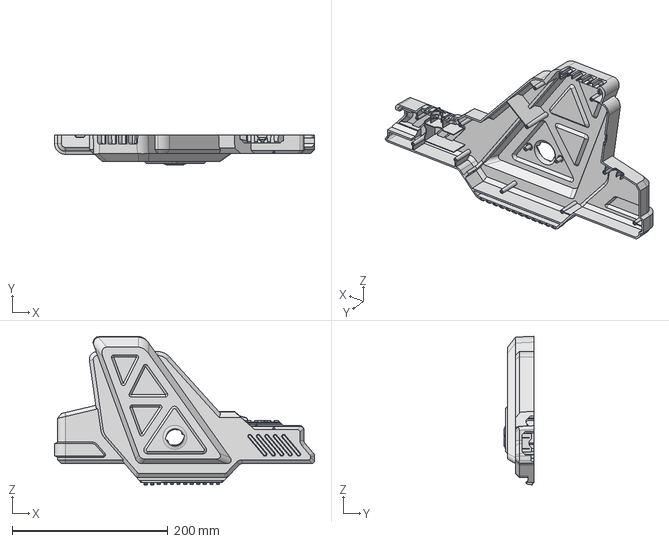
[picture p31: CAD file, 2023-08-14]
STEP/body R.step
334.1 x 38.8 x 190.8 mm

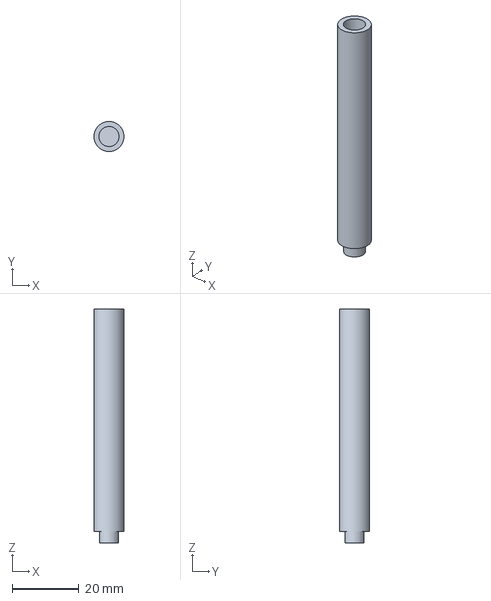
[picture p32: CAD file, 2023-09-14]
CC_BYNCSA_STL_Blaster/CC_BYNCSA_L_Back.3mf
8.99 x 8.99 x 70.0 mm

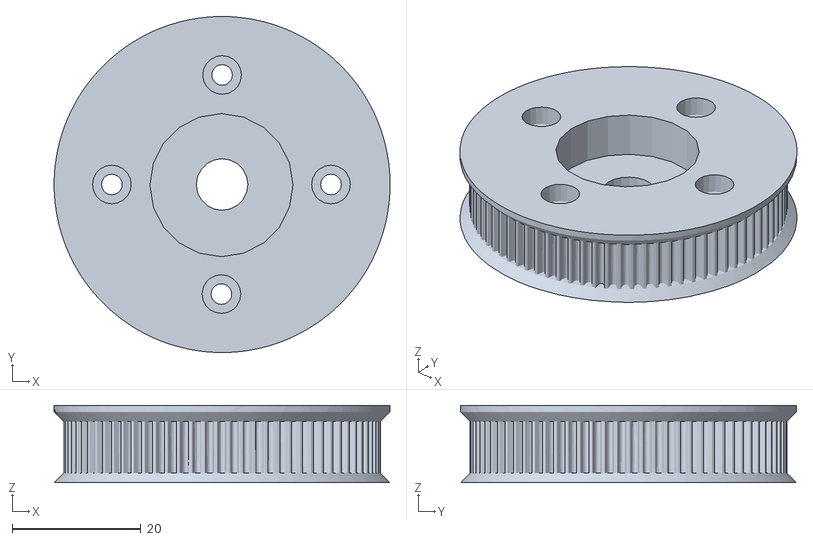
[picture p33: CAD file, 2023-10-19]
CC_BYNCSA_STL_Turret/big_tilt_drive_pulley.stl
52.1 x 52.1 x 12.0

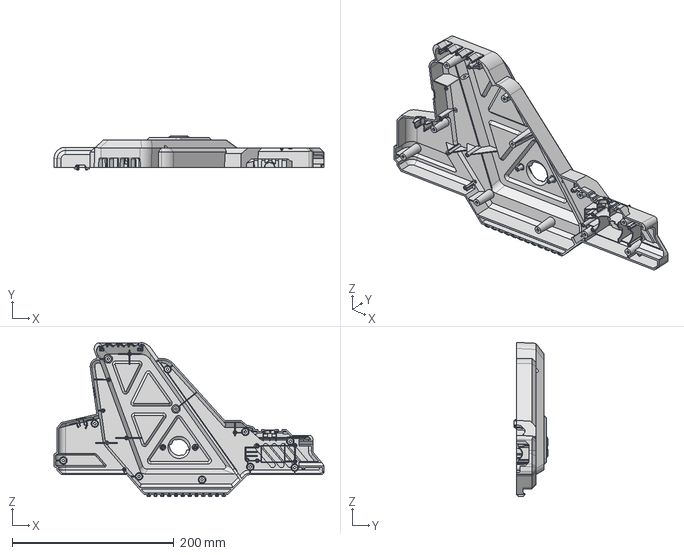
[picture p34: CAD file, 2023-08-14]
STEP/body L.step
334.1 x 41.8 x 190.8 mm

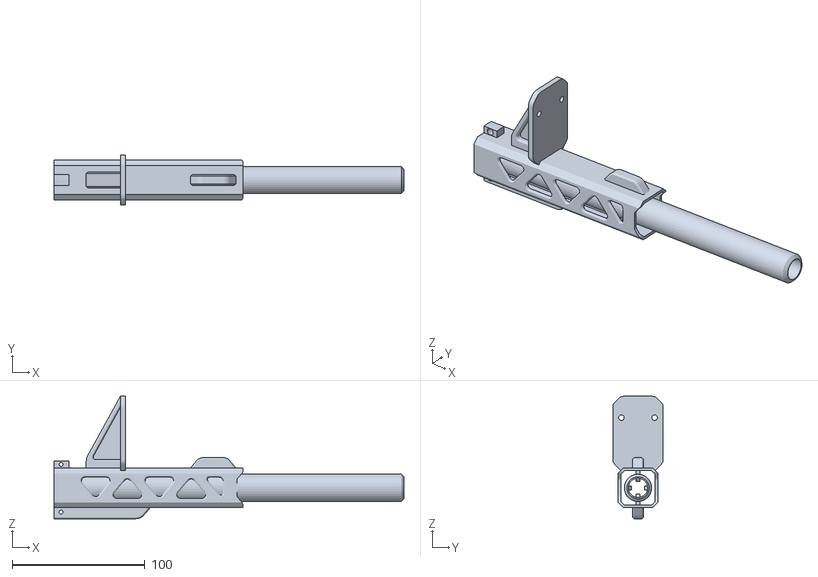
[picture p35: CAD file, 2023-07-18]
CC_BYNCSA_STL_Blaster/CC_BYNCSA_Luxonis_Barrel_01.stl
263.9 x 38.0 x 92.4

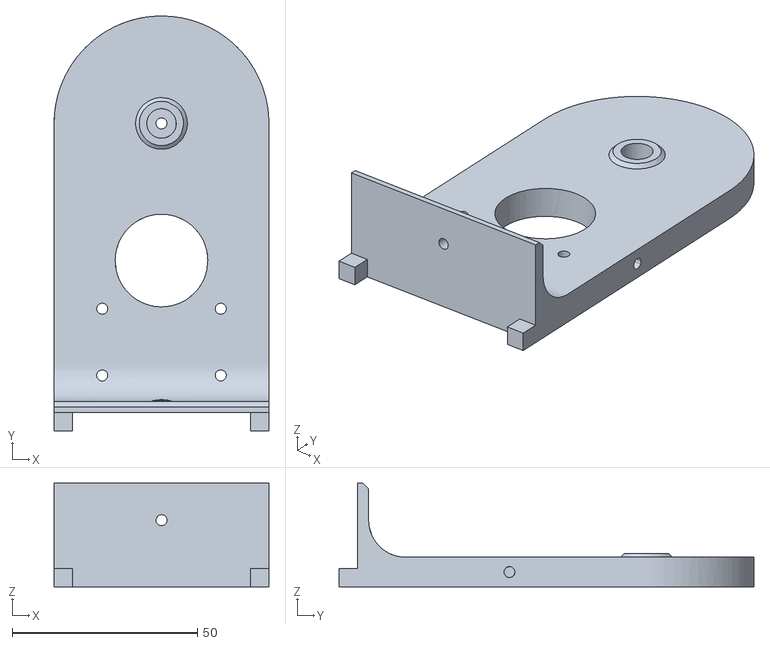
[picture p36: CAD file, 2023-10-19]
CC_BYNCSA_STL_Turret/gear_side_support.stl
58.0 x 112.0 x 28.0

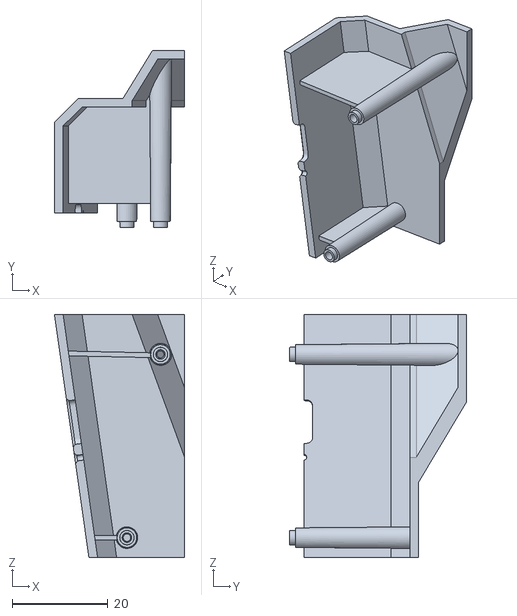
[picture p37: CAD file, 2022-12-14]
CC_BYNCSA_STL_Blaster/CC_BYNCSA_Back_Errata_test_fix.stl
27.2 x 37.0 x 50.9

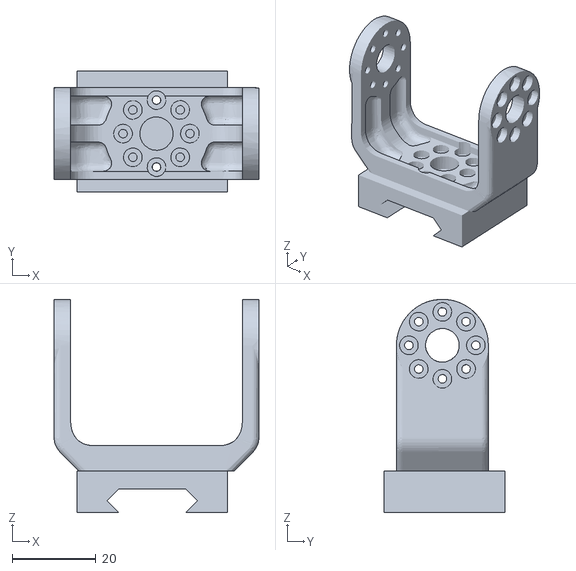
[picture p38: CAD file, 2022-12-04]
CC_BYNCSA_STL_Blaster/CC_BYNCSA_Dynamixel_PicRail.stl
49.0 x 29.0 x 51.0

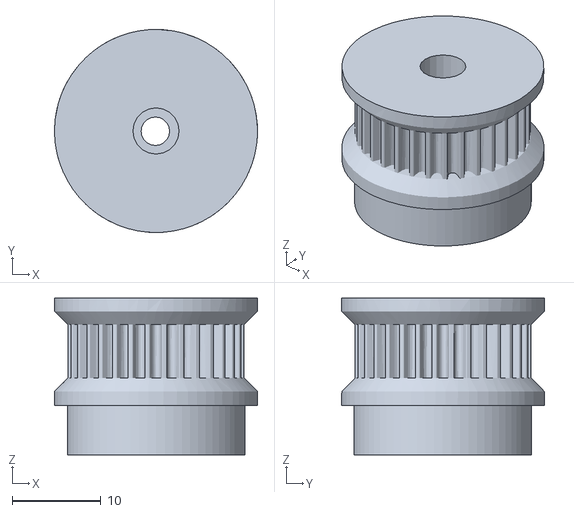
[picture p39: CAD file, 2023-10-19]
CC_BYNCSA_STL_Turret/small_tilt_drive_pulley.stl
22.8 x 22.9 x 17.7

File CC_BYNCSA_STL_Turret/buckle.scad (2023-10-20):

// Parameters
belt_width = 9;           // Width of the timing belt
belt_thickness = 3;       // Combined thickness of two stacked belts
clearance = 0.8;          // Additional clearance for ease of use

// Derived dimensions
outer_width = belt_width + 2 * clearance;
inner_width = belt_width;
section_height = belt_thickness + clearance; // Height of each of the three sections
height = 3 * section_height;  // Total height

module tri_glide_buckle() {
    difference() {
        // Outer shape
        cube([outer_width, height, belt_thickness + clearance], center=true);

        // Inner cutouts
        translate([0, section_height/2, 0])
        cube([inner_width, section_height, belt_thickness + clearance], center=true);
        translate([0, -section_height/2, 0])
        cube([inner_width, section_height, belt_thickness + clearance], center=true);
    }

    // Central divider extended to touch the sides
    cube([belt_thickness-clearance, height, belt_thickness + clearance], center=true);
}

// Call the module to create the buckle
tri_glide_buckle();

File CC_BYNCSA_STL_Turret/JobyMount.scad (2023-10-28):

$fn = 100;

// Parameters for the triangular column
side_length = 20.5;
radius = 4.25;
height = 75;

// Calculate height of the equilateral triangle
h = side_length * sqrt(3) / 2;

// Adjusted positions for circle centers
center1 = [0, h/2 - radius];
center2 = [-6, -h/2 + radius];
center3 = [6, -h/2 + radius];

// Parameters for the tabletop
table_thickness = 5;
hole_spacing = 36; // Adjusted hole spacing
edge_distance = 5;
screw_hole_diameter = 3;
table_side = hole_spacing + 2 * edge_distance;

// Parameters for rounded_triangle
total_length = 18.5; 
ellipse_protrusion = 2.5;
flat_side = total_length - ellipse_protrusion;

module rounded_triangle() {
    // Define the rectangle's left corners
    corner1 = [-flat_side/2, -11/2];
    corner2 = [-flat_side/2, 11/2];

    // Define the center point for the ellipse on the right side
    ellipse_center = [flat_side/2, 0];

    // Use hull() to create the shape with the ellipse for one side
    hull() {
        translate(corner1) circle(0.01); 
        translate(corner2) circle(0.01);  
        translate(ellipse_center + [ellipse_protrusion, 0]) scale([ellipse_protrusion, 11/2]) circle(1); 
    }
}

module tabletop(){
    difference() {
        cube([table_side, table_side, table_thickness], center=true);
        for (i = [-1, 1]) {
            for (j = [-1, 1]) {
                translate([(i * hole_spacing / 2), (j * hole_spacing / 2), table_thickness / 2])  
                cylinder(r=screw_hole_diameter/2, h=100, center=true);
            }
        }
    }
}

union() {
    linear_extrude(height)
    rounded_triangle();
    translate([0, 0, height]);
    tabletop();
}

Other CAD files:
CC_BYNCSA_STL_Blaster/CC_BYNCSA_R_Front.3mf
CC_BYNCSA_STL_Turret/25mm_gear_side_axle.stl
CC_BYNCSA_STL_Turret/17tooth_small_pan_gear.stl
CC_BYNCSA_STL_Turret/Idle_Side_Bearing_Mount.stl
CC_BYNCSA_STL_Blaster/CC_BYNCSA_L_Back.stl
CC_BYNCSA_STL_Blaster/CC_BYNCSA_L_Front.stl
CC_BYNCSA_STL_Blaster/CC_BYNCSA_R_Back.stl
CC_BYNCSA_STL_Blaster/CC_BYNCSA_R_Front.stl
CC_BYNCSA_STL_Turret/Idle_Side_Support.stl
CC_BYNCSA_STL_Turret/SB08_48_Inner_Race_Bottom.stl
CC_BYNCSA_STL_Turret/SB08_48_Inner_Race_Top.stl
CC_BYNCSA_STL_Turret/female_pic_rail_w_screws.3mf
CC_BYNCSA_STL_Turret/female_pic_rail_w_screws.stl
CC_BYNCSA_STL_Turret/pan_base_slew_outer_race.stl
CC_BYNCSA_STL_Turret/primary_mounting_base.stl
CC_BYNCSA_STL_Turret/tilt_u_mount_w_screws.stl

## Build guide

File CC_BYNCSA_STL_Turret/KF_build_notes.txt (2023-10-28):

1. take largest gear put on the tabe
2. set one of the races into the recessed area
3. use 4 m3x20mm screws to prop up the ring to the race height, doesn't matter if they stick out for now. 
4. Set the roller bearings alternating -|-|-|-|-| until you run out. You will have space left on the ring. Expect to cover 75-80% of the ring with rollres
5. Sandwich the top race over top of the bottom race and bearings. 
6. use m3x10 or m3x12 max len to secure every other hole in the ring, do so from the lower side of the ring (bottom of the recessed side)
  flip the ring over, and screw in using the gaps in the bottom plate
  the part of the ring with the little recessed holes should be touching the table. 
 some of the holes won't grip, but hold true and fill them all in anyway, we are using them for temporary structure. 
 remove the screws you used to prop up the original mounting attempt as you go. 
7. mark the holes on the bottom alternating, and then use that to mark the holes top side so you don't miss. I use gold sharpie. 
8. use your thumb to rotate the lazy suzan so you can mark every other hole properly, and get the final few screws in. 
9. You can label start or home so you can know when you rotated all the way 
10. put the m2x20mm you used to prop the mount up away
11. test center the large slew bearing, and the servo hering bone
12 attach the servo hering bond to the mx28
13. use a 1/32 bit to start the first hole in the top place, after centering the ring. Then drill it out with a 1/8 bit. 
14. attach the slew bearing to the top plate hole, drill out the next one directly across. 
15. use 2 m3x20 screws to securethe two, then drill out the remaining odd holes. 
16. use m3x20 screws and nuts to secure all open holes. 
17, push m4 nuts into the tilt wheel assembly. Use an m3 bolt and another nut as a stack up to leverage the nut in place. 
18. Screw the tilt wheel into the u bracket with 4 m3x20 bolts
19. Use 5/64th drill bit to start holes for the servo mount. Go through the holes in servo, then open up with 3/32 bit. 
20. Use 3 nuts as a mount point. Use aluminum spacers to hold the mount up. m2.5x20 should work you should ultimately be able to use 4 spaces to secure.
21. Use m3x10mm to secure the arms to the base. 
22. Press nuts into the cylinder supports. 
23. Press the cylinder supports through the bearing holes, and mount. Sand the cylinders as needed, spot check the fit on the hole + cylinder on the geared side. 
24. Mount the non geared side using m3x20 mm, and an m3x30mm for the geared side. The nut should face the inside of the mechanism. Start the screws into the posts before attempting to mount
25. I had problems with the cylinders so I used threaded spacers instead. The screws I used were 10-32. So I drilled 3/16 holes
26. Start with the geared side, and get it mounted, mount it with the u bracket in place. 
27. Then do the other side. If you use a longer spacer, you can hold it with channel locks, and it gives you room to adjust laterally
28. Print female_pic_rail_w_screws.stl with a scaled z height of 117%
29. Use 2 m3x16 screws and nuts to secure the pic rail to the mount
30. You may want to clean up the pic mount on the Gelblasters with a file to make sure it slides in 
31. Use a rubber mallet gently if you need to coax it in. 
32. Use m3x20 screws to secure the tilt servo, the holes in your revision may be off, so pay attention, if they are off start screws into the left side of the servo, then push through holes on arm, and use the threads on the servo to hold it in place temporarily. Drill out the proper hole pattern on the upper half of the servo. 5/64th will go through the servo threads. Then you can remove it and use 3/32
33. Cut approximately 10 inches of 3d printer timing belt for your tilt mechanism
34. Print a buckle, and use it to tension the tilt mechanism. 
35. Cut approximately 22 inches of 3d printer timing belt for the pan mechanism. 
35. Print a buckle, and use it to tension the pan mechanism
36. Mount the camera to the barrel using two M4x10 screws. 
37. Use flex loom on the camera cable, secure to barrel, and then to U mount with zip ties. 
38. Use a 3/32 drill to bit to clean out 4 holes in a square on the bottom of the turret to facilitate a mount for the Joby tripod
39. You should then be able to mount the turret to the Joby
40. After encasing the wires in the flex loom, make sure to use hot glue to give the trigger wire some relief

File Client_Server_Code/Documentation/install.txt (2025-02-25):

# Current platform is Jetson AGX Xavier with Jetpack 5.1.4 [L4T 35.6.0]
# https://developer.nvidia.com/embedded/jetpack-sdk-514
# https://developer.nvidia.com/embedded/jetson-linux-r3560
#
# You'll need Ubuntu 20.x installed to flash the Jetson with the above software
# Install via: https://developer.nvidia.com/sdk-manager
# https://developer.download.nvidia.com/sdkmanager/redirects/sdkmanager-deb.html

# Install client and server pre-reqs
$ sudo pip3 install -U jetson-stats
$ sudo apt-get install nano
$ sudo apt-get install python3-pip
$ sudo apt-get install python3-pygame
$ sudo apt-get install python3-paho-mqtt
$ sudo apt-get install nvidia-opencv nvidia-opencv-dev
$ sudo apt-get install python3-netifaces
$ sudo apt-get install python3-evdev

# Install DepthAI SDK 
$ sudo python3 -m pip install --extra-index-url https://artifacts.luxonis.com/artifactory/luxonis-python-snapshot-local/ depthai

# Install Dynamixel SDK 
$ git clone --recursive https://github.com/ROBOTIS-GIT/DynamixelSDK.git
$ cd python/
$ sudo python3 setup.py build
$ sudo python3 setup.py install

# Install Mosquito MQTT server
$ sudo apt install mosquitto mosquitto-clients
$ sudo systemctl start mosquitto
$ sudo systemctl enable mosquitto

# Fix permissions for non root use
$ echo 'SUBSYSTEM=="usb", ATTRS{idVendor}=="03e7", MODE="0666"' | sudo tee /etc/udev/rules.d/80-movidius.rules
$ sudo udevadm control --reload-rules && sudo udevadm trigger
$ echo 'SUBSYSTEM=="tty", ATTRS{idVendor}=="0403", ATTRS{idProduct}=="6014", MODE="0666"' | sudo tee /etc/udev/rules.d/80-usbserial.rules
$ sudo udevadm control --reload-rules && udevadm trigger

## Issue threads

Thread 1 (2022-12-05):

internal PCB mount is in wrong spot

MAVProxyUser, 2022-12-05:
The PCB mount does not allow the PCB to me mounted with the USB C charge port facing outward.

The only way to get the board inside, is to allow it to float.

MAVProxyUser, 2022-12-14:
Fix being tested now.
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

MAVProxyUser, 2022-12-14:
Closed in commit: 1a0bdf1e8ede35ba7a7fa92cb56f146b67b1395a  https://github.com/MAVProxyUser/Gelblaster_Wingman/blob/main/CC_BYNCSA_STL_Files/CC_BYNCSA_Back_Errata_test_fix.stl

Closed 2022-12-14.

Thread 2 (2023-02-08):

Lag in camera feed

MAVProxyUser, 2023-02-08:
Ensure connected to USB3 hub:

Note there are both USB 2 & 3 hubs on the Jetson boards.
```
ubuntu@ubuntu:~/yolov7$ sudo lshw -short | grep Hub
/1/2                            bus            USB2.0 Hub
/2/3                            bus            USB3.0 Hub
ubuntu@ubuntu:~/yolov7$ lsusb | grep 0b5c
Bus 002 Device 006: ID 8086:0b5c Intel Corp.
```
You can see above our Realsense cam (USB ID 0b5c) is on bus 2, which is the USB 3.0 hub.

MAVProxyUser, 2023-02-08:
Note the speed difference. The USB3 hub is listed as 5000Mbit/s and the USB2 is 480Mbit/s

ubuntu@ubuntu:~/yolov7$ sudo lshw -C bus
...
  *-usbhost:0
       product: xHCI Host Controller
       vendor: Linux 5.10.104-tegra xhci-hcd
       physical id: 1
       bus info: usb@1
       logical name: usb1
       version: 5.10
       capabilities: usb-2.00
       configuration: driver=hub slots=4 speed=480Mbit/s
     *-usb:0
          description: USB hub
          product: USB2.0 Hub
          vendor: VIA Labs, Inc.
          physical id: 2
          bus info: usb@1:2
          version: 90.23
          capabilities: usb-2.10
          configuration: driver=hub slots=4 speed=480Mbit/s
  *-usbhost:1
       product: xHCI Host Controller
       vendor: Linux 5.10.104-tegra xhci-hcd
       physical id: 2
       bus info: usb@2
       logical name: usb2
       version: 5.10
       capabilities: usb-3.10
       configuration: driver=hub slots=4 speed=10000Mbit/s
     *-usb
          description: USB hub
          product: USB3.0 Hub
          vendor: VIA Labs, Inc.
          physical id: 3
          bus info: usb@2:3
          version: 90.23
          capabilities: usb-3.10
          configuration: driver=hub slots=4 speed=5000Mbit/s

MAVProxyUser, 2023-02-08:
We need to find the optimal camera settings as well
```
#!/usr/bin/python3.8
import pyrealsense2 as rs
import numpy as np
import cv2

pipeline = rs.pipeline()
config = rs.config()

profile = pipeline.start(config)

devices = profile.get_device().query_sensors()
# [<pyrealsense2.sensor: "Stereo Module">, <pyrealsense2.sensor: "RGB Camera">, <pyrealsense2.sensor: "Motion Module">]
print(devices)

# https://intelrealsense.github.io/librealsense/python_docs/_generated/pyrealsense2.options.html
depth_sensor = profile.get_device().first_depth_sensor()
print(depth_sensor.get_supported_options())

color_sensor = profile.get_device().first_color_sensor()
print(color_sensor.get_supported_options())

motion_sensor = profile.get_device().first_motion_sensor()
print(motion_sensor.get_supported_options())
```

My current settings:
```
[<pyrealsense2.sensor: "Stereo Module">, <pyrealsense2.sensor: "RGB Camera">, <pyrealsense2.sensor: "Motion Module">]
[<option.exposure: 3>, <option.gain: 4>, <option.enable_auto_exposure: 10>, <option.visual_preset: 12>, <option.laser_power: 13>, <option.emitter_enabled: 18>, <option.frames_queue_size: 19>, <option.asic_temperature: 23>, <option.error_polling_enabled: 24>, <option.projector_temperature: 25>, <option.output_trigger_enabled: 26>, <option.depth_units: 28>, <option.stereo_baseline: 40>, <option.inter_cam_sync_mode: 42>, <option.emitter_on_off: 46>, <option.global_time_enabled: 53>, <option.emitter_always_on: 71>, <option.thermal_compensation: 72>, <option.hdr_enabled: 76>, <option.sequence_name: 77>, <option.sequence_size: 78>, <option.sequence_id: 79>, <option.emitter_frequency: 93>]
[<option.backlight_compensation: 0>, <option.brightness: 1>, <option.contrast: 2>, <option.exposure: 3>, <option.gain: 4>, <option.gamma: 5>, <option.hue: 6>, <option.saturation: 7>, <option.sharpness: 8>, <option.white_balance: 9>, <option.enable_auto_exposure: 10>, <option.enable_auto_white_balance: 11>, <option.frames_queue_size: 19>, <option.power_line_frequency: 22>, <option.auto_exposure_priority: 30>, <option.global_time_enabled: 53>]
[<option.frames_queue_size: 19>, <option.enable_motion_correction: 29>, <option.global_time_enabled: 53>]
```
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
https://support.intelrealsense.com/hc/en-us/community/posts/1500001025701-Cannot-get-stable-framerate-on-RealSense-D455

MAVProxyUser, 2023-09-12:
@cherbini this applies to Luxonis lag too. Make sure you are using USB 3.

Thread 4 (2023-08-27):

Current 3d printer setup for butter prints.

MAVProxyUser, 2023-08-27:
Kevin's setup:

PrintDry PRO 3 Filament Drying System PrintDry PRO 3 + Additional Chamber Kit + Large Spool Kit
https://www.printdry.com/product/printdry-filament-dryer-pro3/
https://www.printdry.com/product/large-spool-kit-dryer-pro/
https://www.printdry.com/product/additional-chamber-kit-dryer-pro/

Vector 3d Cauliflower
https://vector3d.co.uk/product/califlower/
https://www.youtube.com/watch?v=dbWAhb40kG4
https://www.youtube.com/watch?v=QZtND2D1U1A

Volcano V6 Nozzle Adapter
https://www.ebay.com/itm/185689353308

.5mm Deez Tungsten "Cat Butthole" V1 nozzle by PrintyPlease
https://www.printyplease.uk/DeezV1
(V1 is not "high flow" It is still fully Tungsten Carbide)

Ender 5 S1
https://www.microcenter.com/product/661055/creality-ender-5-s1-3d-printer

Ender 5 S1 Auto Bed Leveling Fix
https://www.printables.com/model/415792-ender-5-s1-auto-bed-leveling-fix

Some spacers and brackets for Ender 5 S1 to K1 hotend mod
https://www.printables.com/model/551914-some-spacers-and-brackets-for-ender-5-s1-to-k1-hot

Details: Ender 5 S1 with the K1 hotend (mod)
https://www.reddit.com/r/ender5/comments/158nsai/ender_5_s1_with_the_k1_hotend/

Polymer PA6-CF
https://www.amazon.com/Polymaker-PA6-CF-Filament-Carbon-Cardboard/dp/B09MTBF55V/
https://www.amazon.com/Polymaker-PA6-CF-Filament-Carbon-Cardboard/dp/B0B45TQRK1/

Orca Slicer 1.6.4
https://github.com/SoftFever/OrcaSlicer
Orca Slicer Settings
[Orca Slicer Settings.zip](https://github.com/MAVProxyUser/Gelblaster_Wingman/files/12447093/Orca.Slicer.Settings.zip)

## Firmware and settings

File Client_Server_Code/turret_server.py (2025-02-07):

#!/usr/bin/env python
# -*- coding: utf-8 -*-

import sys
import time
import threading
import paho.mqtt.client as mqtt
import json
import platform
import socket
import netifaces
import cv2
import numpy as np
import os
import subprocess
import logging
import depthai as dai
import traceback
import math

# Configure logging
logging.basicConfig(level=logging.DEBUG, format='%(asctime)s - %(levelname)s - %(message)s')

# Platform detection
current_platform = platform.system()
print(f"Running on {current_platform}", flush=True)

# Camera initialization settings for macOS
if platform.system() == 'Darwin':
    print("\nMacOS Camera Setup Instructions:", flush=True)
    print("1. Open System Preferences", flush=True)
    print("2. Go to Security & Privacy -> Privacy -> Camera", flush=True)
    print("3. Ensure Terminal has camera access", flush=True)
    print("4. If Terminal isn't listed, try running this command first:", flush=True)
    print("   tccutil reset Camera\n", flush=True)

    os.environ['OPENCV_AVFOUNDATION_SKIP_AUTH'] = '0'
    os.environ['OPENCV_VIDEOIO_DEBUG'] = '1'

# Common imports for all platforms
if current_platform == 'Linux':
    import Jetson.GPIO as GPIO
    import depthai as dai
    from dynamixel_sdk import *
    import serial.tools.list_ports

# Add cleanup at start to ensure GPIO is released
if current_platform == 'Linux':
    try:
        if GPIO.getmode() is not None:  # Only cleanup if GPIO is initialized
            GPIO.cleanup()
    except:
        pass
    GPIO.setmode(GPIO.BOARD)
    GPIO.setwarnings(False)

    # Initialize relay pin
    RELAY_PIN = 7  # GPIO9
    GPIO.setup(RELAY_PIN, GPIO.OUT)
    GPIO.output(RELAY_PIN, GPIO.HIGH)  # Start with relay deactivated
    print(f"Initialized relay pin {RELAY_PIN} to HIGH (deactivated)", flush=True)

# MQTT Topics - Update these to match the client
MQTT_TOPIC_CONTROL = "dpad/commands"   # Changed to match client
MQTT_TOPIC_CAMERA = "camera/feed"
MQTT_TOPIC_BBOX = "camera/bbox"
MQTT_TOPIC_SERVO_STATUS = "servo/status"
MQTT_TOPIC_PLATFORM = "server/platform"
MQTT_TOPIC_PLATFORM_REQUEST = "server/platform_request"
MQTT_TOPIC_DEPTH = "camera/depth"
MQTT_TOPIC_RELAY = "relay/command"
MQTT_TOPIC_COMMAND = "dpad/commands"   # Changed to match client
RELAY_ACTIVATE = 'off'    # Relay is "normally closed" - sending 'off' activates it
RELAY_DEACTIVATE = 'on'   # Sending 'on' deactivates the normally closed relay

# Add with other MQTT topics at the top

# First define the constants
POSITION_CENTER = 2048     # Center position
HOME_PAN_ANGLE = 0.0      # Default home position for pan (center)
HOME_TILT_ANGLE = 0.0     # Default home position for tilt (center)

# Color detection constants
# Green LED detection
GREEN_LOW = np.array([45, 50, 150])    # Higher value minimum for LED brightness
GREEN_HIGH = np.array([85, 255, 255])   # Keep upper bound the same

# Purple LED detection
PURPLE_LOW = np.array([130, 50, 150])   # Purple/Violet hue range with same brightness requirements
PURPLE_HIGH = np.array([170, 255, 255])

# Yellow LED detection - Adjusted for very bright, whitish-yellow LEDs
YELLOW_LOW = np.array([20, 10, 220])    # Very low saturation minimum, very high brightness requirement
YELLOW_HIGH = np.array([40, 150, 255])  # Limited maximum saturation to catch whitish yellows

# Add color selection to latest_command structure
latest_command = {
    'auto_mode': False,
    'pan_angle': HOME_PAN_ANGLE,
    'tilt_angle': HOME_TILT_ANGLE,
    'command_received': False,
    'selected_color': 'green'  # Default to green
}

# Dynamixel Configuration
ADDR_TORQUE_ENABLE = 64               # Control table address for torque enable
ADDR_OPERATING_MODE = 11              # Control table address for operating mode
ADDR_GOAL_POSITION = 116             # Control table address for goal position
ADDR_PRESENT_POSITION = 132          # Control table address for present position
ADDR_GOAL_CURRENT = 102              # Control table address for goal current (torque)
ADDR_RESET = 117                     # Control table address for factory reset
LEN_GOAL_POSITION = 4                # Data length for goal position
DXL1_ID = 1                          # Pan servo ID
DXL2_ID = 2                          # Tilt servo ID
BAUDRATE = 1000000                   # Default baudrate
PROTOCOL_VERSION = 2.0               # Protocol version
TORQUE_ENABLE = 1                    # Value for enabling torque
TORQUE_DISABLE = 0                   # Value for disabling torque
DXL_MOVING_STATUS_THRESHOLD = 20     # Threshold for detecting movement
DXL_GOAL_CURRENT = 500              # Torque limit (0-1193)

# Operating mode settings
OPERATING_MODE = 4         # Extended position control mode (multi-turn)
MAX_POSITION_VALUE = 4095  # Maximum position value
MIN_POSITION_VALUE = 0     # Minimum position value
COMM_SUCCESS = 0          # Communication success result value

# Then define the global variables that use these constants
command_lock = threading.Lock()
frame_lock = threading.Lock()
detection_lock = threading.Lock()

# Rest of the global variables
latest_frame = None
latest_detection = None
running = True
client_connected = False
home_pan_position = None
home_tilt_position = None
tof = 0.0
sensitivity = 1.0
last_relay_change = 0
pan_servo = None
tilt_servo = None
cap = None
q_rgb = None
device = None
current_pan_angle = HOME_PAN_ANGLE
current_tilt_angle = HOME_TILT_ANGLE
current_speed = 0
current_auto_mode = False

# Then the rest of the constants
PAN_MIN_ANGLE = -540.0  # Triple range for pan (1.5 full rotations)
PAN_MAX_ANGLE = 540.0   # Triple range for pan (1.5 full rotations)
TILT_MIN_ANGLE = -45.0  # Keep current tilt angle limits
TILT_MAX_ANGLE = 45.0   # Keep current tilt angle limits

# Near the top of the file with other constants
PAN_ANGLE_PER_PIXEL = 0.2  # Increased for faster response
TILT_ANGLE_PER_PIXEL = 0.1  # Keep tilt speed the same

# Servo Control Parameters
MAX_SPEED_DEG_PER_SEC = 720.0  # Increased for faster pan movement
UPDATE_RATE_HZ = 50  # Control loop update rate
MAX_SPEED = MAX_SPEED_DEG_PER_SEC / UPDATE_RATE_HZ  # Max speed per update
MIN_CORRECTION = 0.1  # Minimum correction to apply (degrees)

# Add these with the other Dynamixel Configuration constants
ADDR_POSITION_P_GAIN = 84    # Control table address for Position P Gain
ADDR_POSITION_I_GAIN = 82    # Control table address for Position I Gain  
ADDR_POSITION_D_GAIN = 80    # Control table address for Position D Gain

# Add these constants at the top with other constants
PAN_MIN_POSITION = -6144     # Restored extended range for pan (1.5 rotations CCW)
PAN_MAX_POSITION = 6144      # Restored extended range for pan (1.5 rotations CW)
TILT_MIN_POSITION = 0        # Keep standard range for tilt
TILT_MAX_POSITION = 4095     # Keep standard range for tilt

# Add at the top with other globals
previous_error_x = 0
previous_error_y = 0

# Add with other globals at the top
sensitivity = 1.0  # Default sensitivity

# Move this function up, before servo_update_thread
def angle_to_servo_position(servo_id, angle):
    """Convert angle in degrees to servo position"""
    if servo_id == DXL1_ID:  # Pan servo
        # Limit pan angle
        angle = min(max(angle, PAN_MIN_ANGLE), PAN_MAX_ANGLE)
        # Convert angle to position (4095 per 360 degrees)
        return int(2048 + (angle * 4095 / 360.0))
    else:  # Tilt servo
        # Limit tilt angle
        angle = min(max(angle, TILT_MIN_ANGLE), TILT_MAX_ANGLE)
        return int(2048 + (angle * 2048 / 90.0))

def find_dynamixel_port():
    """Find the Dynamixel U2D2 controller port."""
    try:
        ports = list(serial.tools.list_ports.comports())
        print(f"Available ports: {[port.device for port in ports]}", flush=True)
        
        # First try to find U2D2 by USB ID
        for port in ports:
            if "FT232R" in port.description or "U2D2" in port.description:
                print(f"Found potential U2D2 device at {port.device}", flush=True)
                port_handler = PortHandler(port.device)
                if port_handler.openPort():
                    print(f"Opened port {port.device}", flush=True)
                    if port_handler.setBaudRate(BAUDRATE):
                        print(f"Set baud rate to {BAUDRATE}", flush=True)
                        packet_handler = PacketHandler(PROTOCOL_VERSION)
                        for dxl_id in [DXL1_ID, DXL2_ID]:
                            dxl_model_number, dxl_comm_result, dxl_error = packet_handler.ping(port_handler, dxl_id)
                            if dxl_comm_result == COMM_SUCCESS:
                                print(f"Successfully pinged Dynamixel ID {dxl_id} on port {port.device}", flush=True)
                                return port_handler, packet_handler
                    port_handler.closePort()

        # If U2D2 not found by description, try ttyUSB devices
        for port in ports:
            if "ttyUSB" in port.device:
                print(f"Trying USB device at {port.device}", flush=True)
                port_handler = PortHandler(port.device)
                if port_handler.openPort():
                    if port_handler.setBaudRate(BAUDRATE):
                        packet_handler = PacketHandler(PROTOCOL_VERSION)
                        for dxl_id in [DXL1_ID, DXL2_ID]:
                            dxl_model_number, dxl_comm_result, dxl_error = packet_handler.ping(port_handler, dxl_id)
                            if dxl_comm_result == COMM_SUCCESS:
                                return port_handler, packet_handler
                    port_handler.closePort()

        print("Could not find U2D2 device", flush=True)
        return None, None

    except Exception as e:
        print(f"Error finding Dynamixel port: {e}", flush=True)
        traceback.print_exc()
        return None, None

def initialize_servos(portHandler, packetHandler):
    """Initialize servos and store their initial positions"""
    global initial_pan_position, initial_tilt_position
    
    try:
        # Read control table items to debug servo configuration
        def read_control_table(dxl_id, address, size=1):
            if size == 1:
                result, comm_result, error = packetHandler.read1ByteTxRx(portHandler, dxl_id, address)
            elif size == 2:
                result, comm_result, error = packetHandler.read2ByteTxRx(portHandler, dxl_id, address)
            elif size == 4:
                result, comm_result, error = packetHandler.read4ByteTxRx(portHandler, dxl_id, address)
            if comm_result != COMM_SUCCESS or error != 0:
                logging.error(f"Failed to read address {address} from servo {dxl_id}:")
                if comm_result != COMM_SUCCESS:
                    logging.error(f"Comm Error: {packetHandler.getTxRxResult(comm_result)}")
                if error != 0:
                    logging.error(f"Packet Error: {packetHandler.getRxPacketError(error)}")
                return None
            return result

        # Debug servo 2 (tilt) configuration
        logging.info("Reading tilt servo configuration:")
        operating_mode = read_control_table(DXL2_ID, ADDR_OPERATING_MODE)
        logging.info(f"Operating mode: {operating_mode}")
        
        # Try to read position limits if they exist
        min_pos = read_control_table(DXL2_ID, 52, size=4)  # Min position limit
        max_pos = read_control_table(DXL2_ID, 48, size=4)  # Max position limit
        logging.info(f"Position limits from servo: min={min_pos}, max={max_pos}")
        
        # Initialize pan servo (DXL1_ID)
        logging.info("Initializing servo 1")
        
        # Disable torque to allow configuration
        packetHandler.write1ByteTxRx(portHandler, DXL1_ID, ADDR_TORQUE_ENABLE, TORQUE_DISABLE)
        time.sleep(0.1)
        
        # Set operating mode to extended position control (multi-turn)
        packetHandler.write1ByteTxRx(portHandler, DXL1_ID, ADDR_OPERATING_MODE, 4)
        time.sleep(0.1)
        
        # Set torque limit
        packetHandler.write2ByteTxRx(portHandler, DXL1_ID, ADDR_GOAL_CURRENT, DXL_GOAL_CURRENT)
        time.sleep(0.1)
        
        # Enable torque
        packetHandler.write1ByteTxRx(portHandler, DXL1_ID, ADDR_TORQUE_ENABLE, TORQUE_ENABLE)
        logging.info("Successfully initialized servo 1")

        # Initialize tilt servo (DXL2_ID)
        logging.info("Initializing servo 2")
        
        # Disable torque to allow configuration
        packetHandler.write1ByteTxRx(portHandler, DXL2_ID, ADDR_TORQUE_ENABLE, TORQUE_DISABLE)
        time.sleep(0.1)
        
        # Set operating mode to extended position control (multi-turn)
        packetHandler.write1ByteTxRx(portHandler, DXL2_ID, ADDR_OPERATING_MODE, 4)
        time.sleep(0.1)
        
        # Try to read current position before setting limits
        current_pos = read_control_table(DXL2_ID, ADDR_PRESENT_POSITION, size=4)
        logging.info(f"Current position before configuration: {current_pos}")
        
        # Set torque limit
        packetHandler.write2ByteTxRx(portHandler, DXL2_ID, ADDR_GOAL_CURRENT, DXL_GOAL_CURRENT)
        time.sleep(0.1)
        
        # Enable torque
        packetHandler.write1ByteTxRx(portHandler, DXL2_ID, ADDR_TORQUE_ENABLE, TORQUE_ENABLE)
        logging.info("Successfully initialized servo 2")

        # Read initial positions
        dxl_present_position1, dxl_comm_result1, dxl_error1 = packetHandler.read4ByteTxRx(
            portHandler, DXL1_ID, ADDR_PRESENT_POSITION)
        dxl_present_position2, dxl_comm_result2, dxl_error2 = packetHandler.read4ByteTxRx(
            portHandler, DXL2_ID, ADDR_PRESENT_POSITION)
        
        if dxl_comm_result1 == COMM_SUCCESS and dxl_comm_result2 == COMM_SUCCESS:
            initial_pan_position = dxl_present_position1
            initial_tilt_position = dxl_present_position2
            
            logging.info(f"Initialized servos at positions - Pan: {initial_pan_position}, Tilt: {initial_tilt_position}")
            return True
            
        return False

    except Exception as e:
        logging.error(f"Error in initialize_servos: {e}")
        return False

def initialize_servo(dxl_id):
    """Initialize a servo with proper settings."""
    try:
        # 1. Disable torque to allow setting operating mode
        dxl_comm_result, dxl_error = packetHandler.write1ByteTxRx(
            portHandler, dxl_id, ADDR_TORQUE_ENABLE, TORQUE_DISABLE)
        if dxl_comm_result != COMM_SUCCESS:
            logging.error(f"Failed to disable torque on ID {dxl_id}")
            return False

        # 2. Set operating mode (Extended Position for pan, Position for tilt)
        mode = OPERATING_MODE if dxl_id == DXL1_ID else 3  # 4 for Extended Position, 3 for Position
        dxl_comm_result, dxl_error = packetHandler.write1ByteTxRx(
            portHandler, dxl_id, ADDR_OPERATING_MODE, mode)
        if dxl_comm_result != COMM_SUCCESS:
            logging.error(f"Failed to set operating mode on ID {dxl_id}")
            return False

        # 3. Set goal current (torque limit)
        dxl_comm_result, dxl_error = packetHandler.write2ByteTxRx(
            portHandler, dxl_id, ADDR_GOAL_CURRENT, DXL_GOAL_CURRENT)
        if dxl_comm_result != COMM_SUCCESS:
            logging.error(f"Failed to set goal current on ID {dxl_id}")
            return False

        # 4. Re-enable torque
        dxl_comm_result, dxl_error = packetHandler.write1ByteTxRx(
            portHandler, dxl_id, ADDR_TORQUE_ENABLE, TORQUE_ENABLE)
        if dxl_comm_result != COMM_SUCCESS:
            logging.error(f"Failed to enable torque on ID {dxl_id}")
            return False

        logging.info(f"Successfully initialized servo ID {dxl_id}")
        return True

    except Exception as e:
        logging.error(f"Error initializing servo ID {dxl_id}: {e}")
        return False

def read_servo_position(dxl_id, retries=3):
    """Read the current position of a servo with retries"""
    for attempt in range(retries):
        try:
            # Read present position
            dxl_present_position, dxl_comm_result, dxl_error = packetHandler.read4ByteTxRx(
                portHandler, dxl_id, ADDR_PRESENT_POSITION)
            
            if dxl_comm_result == COMM_SUCCESS and dxl_error == 0:
                # Handle overflow for values near max uint32
                if dxl_present_position > 0xFFFF0000:  # If value is close to uint32 max
                    dxl_present_position = dxl_present_position - 0xFFFFFFFF - 1  # Convert to negative
                
                logging.debug(f"Successfully read position for servo {dxl_id}: {dxl_present_position}")
                return dxl_present_position
            else:
                logging.warning(f"Failed to read servo {dxl_id} position on attempt {attempt + 1}:")
                logging.warning(f"Comm result: {packetHandler.getTxRxResult(dxl_comm_result)}")
                logging.warning(f"Error: {packetHandler.getRxPacketError(dxl_error)}")
                
        except Exception as e:
            logging.error(f"Error reading servo {dxl_id} position on attempt {attempt + 1}: {e}")
            
        # Small delay before retry
        time.sleep(0.1)
    
    logging.error(f"Failed to read servo {dxl_id} position after {retries} attempts")
    return None

def servo_position_to_angle(servo_id, position):
    """Convert servo position to angle in degrees"""
    if servo_id == DXL1_ID:  # Pan servo
        # Pan servo: 2048 is center (0°), multi-turn enabled
        return (position - 2048) * (360.0 / 4095)
    else:  # Tilt servo
        # Tilt servo: 2048 is 0°, range is -45° to +45°
        return (position - 2048) * (90.0 / 2048)

# Add at the top with other globals
last_relay_change = 0
RELAY_DEBOUNCE_TIME = 0.1  # 100ms debounce

def on_connect(client, userdata, flags, rc):
    """Callback when client connects to MQTT broker"""
    global client_connected
    logging.info(f"Connected with result code {rc}")
    
    if rc == 0:  # Only set connected if connection was successful
        # Subscribe to all required topics
        client.subscribe([
            (MQTT_TOPIC_CONTROL, 0),
            (MQTT_TOPIC_COMMAND, 0),
            (MQTT_TOPIC_RELAY, 0),
            ("server/sensitivity", 0)  # Add subscription for sensitivity adjustments
        ])
        logging.info("Subscribed to control topics")
        
        # Initialize with auto mode off and no commands received
        global latest_command
        latest_command = {
            'auto_mode': False,
            'pan_angle': HOME_PAN_ANGLE,
            'tilt_angle': HOME_TILT_ANGLE,
            'command_received': False,
            'selected_color': 'green'  # Default to green
        }
        
        # Set client_connected flag
        client_connected = True
        logging.info("Client connected and initialized")
    else:
        logging.error(f"Failed to connect with result code {rc}")
        client_connected = False

def on_command(client, userdata, message):
    try:
        logging.debug(f"Received message on topic {message.topic}")
        logging.debug(f"Message payload: {message.payload}")
        
        if message.topic == "server/sensitivity":
            handle_sensitivity_update(message)
            return
            
        if message.topic == MQTT_TOPIC_RELAY:
            relay_command = message.payload.decode('utf-8')
            if relay_command == "on":
                trigger_relay()
                logging.info("Relay triggered")
            return

        # For all other commands, expect JSON
        payload = json.loads(message.payload)
        logging.debug(f"Processing command: {payload}")

        with command_lock:
            # Handle keyboard commands
            if message.topic == MQTT_TOPIC_COMMAND:
                if 'selected_color' in payload:
                    latest_command['selected_color'] = payload['selected_color']
                    logging.info(f"Color selection changed to: {payload['selected_color']}")
                if 'pan_delta' in payload:
                    current_pan = latest_command.get('pan_angle', 0)
                    latest_command['pan_angle'] = current_pan + payload['pan_delta']
                    latest_command['command_received'] = True
                    logging.info(f"Pan delta {payload['pan_delta']} applied, new angle: {latest_command['pan_angle']}")
                if 'tilt_delta' in payload:
                    current_tilt = latest_command.get('tilt_angle', 0)
                    latest_command['tilt_angle'] = current_tilt + (payload['tilt_delta'] * 0.0625)  # Reduced to 1/16
                    latest_command['command_received'] = True
                    logging.info(f"Tilt delta {payload['tilt_delta'] * 0.0625} applied, new angle: {latest_command['tilt_angle']}")
                if 'auto_mode' in payload:
                    latest_command['auto_mode'] = payload['auto_mode']
                    latest_command['command_received'] = True
                    logging.info(f"Auto mode set to {payload['auto_mode']} from command topic")

        # Debug the final command state
        logging.debug(f"Current command state: {latest_command}")

    except Exception as e:
        logging.error(f"Error processing command: {e}")
        logging.error(traceback.format_exc())

def handle_sensitivity_update(message):
    """Handle updates to the sensitivity value"""
    global sensitivity
    try:
        payload = json.loads(message.payload)
        sensitivity = payload.get('sensitivity', 1.0)
        print(f"Updated sensitivity to: {sensitivity}", flush=True)
    except Exception as e:
        print(f"Error processing sensitivity update: {e}", flush=True)
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

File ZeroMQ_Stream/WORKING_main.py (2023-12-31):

# File: main.py

import time
import concurrent.futures
import queue
import threading
import cv2
import users
import numpy as np
import apriltag
import Jetson.GPIO as GPIO
from dynamixel_controller import DynamixelController
from motion_tracker import MotionTracker
from coordinate_system import CoordinateSystem

class Application:
    def __init__(self):
        # Create settings window
        self.device_port = "/dev/ttyUSB0"
        self.baudrate = 1000000 
        self.pan_servo_id = 1
        self.tilt_servo_id = 2
        self.tilt_offset = 10
        self.relay_pin = 7
        GPIO.setmode(GPIO.BOARD)
        GPIO.setup(self.relay_pin, GPIO.OUT)
        GPIO.output(self.relay_pin, GPIO.LOW)  # Setting it to LOW initially

        self.frame_semaphore = threading.Semaphore()
        self.current_frame = None

        self.nnPath = "models/yolo-v3-tiny-tf_openvino_2021.4_6shave.blob"  # Set the correct path to the YOLO model blob file

        # Initialize components
        self.dynamixel_controller = DynamixelController(self.device_port, self.baudrate, self.pan_servo_id, self.tilt_servo_id)
        self.motion_tracker = MotionTracker(self.nnPath)
        self.coordinate_system = CoordinateSystem()
        self.capturing = True  # This indicates if the capture_frames method is still capturing frames

        self._terminate = False  # Add this line to initialize the attribute
        self.frame_queue = queue.Queue(maxsize=1000)
        self.camera_ready = threading.Event()

        # Initialize Kalman filter
        self.kalman = cv2.KalmanFilter(4, 2)
        self.kalman.measurementMatrix = np.array([[1, 0, 0, 0], [0, 1, 0, 0]], np.float32)
        self.kalman.transitionMatrix = np.array([[1, 0, 1, 0], [0, 1, 0, 1], [0, 0, 1, 0], [0, 0, 0, 1]], np.float32)
        self.process_noise_cov = 6
        self.measurement_noise_cov = 4
        self.kalman.processNoiseCov = np.eye(4, dtype=np.float32) * self.process_noise_cov
        self.kalman.measurementNoiseCov = np.eye(2, dtype=np.float32) * self.measurement_noise_cov
        self.kalman.statePost = np.zeros((4,1), np.float32)
        self.kalman.statePre = np.zeros((4,1), np.float32)
        self.kalman.errorCovPost = np.eye(4, dtype=np.float32)
        self.kalman.errorCovPre = np.eye(4, dtype=np.float32)


        self.MAX_VALID_PREDICTION = 1000
        self.MIN_VALID_PREDICTION = 0

        self.display_queue = queue.Queue(maxsize=100)

        # Set home and detection timer
        self.home_position = (self.dynamixel_controller.PAN_CENTER_POSITION, self.dynamixel_controller.TILT_CENTER_POSITION)
        print(f"Home Position: {self.home_position}", flush=True)
        self.last_positions = []
        self.start_time = None
        self.last_centroid = None
        self.THRESHOLD_DISTANCE = 5
        self.TIME_LIMIT = 3.0

        self.april_detector = apriltag.Detector()
        self.april_tag_visible = False
        self.flip_horizontal = 1
        self.flip_vertical = 1
        self.tag_confidence_threshold = .7
        self.servo_scale = 1
        self.show_frame = 1
        self.servo_speed = 200
        self.reverse_pan = 0
        self.reverse_tilt = 0
        self.prev_x_pixels = None
        self.prev_y_pixels = None
        self.prev_vx_pixels = None
        self.prev_vy_pixels = None

    def stop(self):
        self._terminate = True

    def monitor_queue(self):
        while not self._terminate:
            print(f"Frame queue size: {self.frame_queue.qsize()}")
            time.sleep(1)

    def capture_frames(self, frame_queue):
        try:
            while self.capturing and not self._terminate:
                for frame, detections in self.motion_tracker.run():
                    frame_queue.put((frame, detections))
                    time.sleep(0.033)  # Introduce a 30 fps rate (or adjust accordingly)
            print("Capture Frames method has stopped.")
        except Exception as e:
            print(f"Error in capture_frames: {e}")
        finally:
            self.capturing = False
            self.camera_ready.set()

    def process_frames(self, frame_queue):
        try:
            while self.capturing or not frame_queue.empty():
                frame, detections = frame_queue.get()
                if frame is not None and frame.any():
                    print("Processing a frame...")
    
                    # Draw detections on frame
                    for detection in detections:
                        xmin = int(detection.xmin * frame.shape[1])
                        ymin = int(detection.ymin * frame.shape[0])
                        xmax = int(detection.xmax * frame.shape[1])
                        ymax = int(detection.ymax * frame.shape[0])
                        cv2.rectangle(frame, (xmin, ymin), (xmax, ymax), (0, 255, 0), 2)  # Draw detection in green
                        
                    # Set the current frame
                    self.current_frame = frame
        except Exception as e:
            print(f"Error in process_frames: {e}")

    def update_kalman_filter(self):
        self.kalman.processNoiseCov = np.eye(4, dtype=np.float32) * self.process_noise_cov
        self.kalman.measurementNoiseCov = np.eye(2, dtype=np.float32) * self.measurement_noise_cov

    def display_frames(self, display_queue):
        self.camera_ready.wait()
        while not display_queue.empty():
            frame = display_queue.get()
            print("Displaying a frame...")
            cv2.imshow("Frame", frame)
            if cv2.waitKey(1) == ord('q'):
                break
        print(f"Display Queue Size (End of Display): {display_queue.qsize()}",flush=True)

    def activate_relay(self, duration=2):
            GPIO.output(self.relay_pin, GPIO.HIGH)
            time.sleep(duration)
            GPIO.output(self.relay_pin, GPIO.LOW)

    def set_servo_speed(self, servo_id, speed):
        try:
            self.dynamixel_controller.set_speed(servo_id, speed)
        except Exception as e:
            print(f"Failed to set servo speed for servo ID {servo_id}: {e}", flush=True)

    def clamp_servo_position(self, goal, min_position, max_position):
        return self.dynamixel_controller.clamp_servo_position(goal, min_position, max_position)

    def get_bbox_coordinates(self, detection):
        return [detection.xmin, detection.ymin, detection.xmax, detection.ymax]

    def draw_centroid(self, frame, centroid):
        centroid_px = (int(centroid[0] * frame.shape[1]), int(centroid[1] * frame.shape[0]))
        cv2.circle(frame, centroid_px, 5, (0, 255, 0), -1) #GREEN

    def draw_prediction(self, frame, prediction):
        prediction_px = (int(prediction[0]), int(prediction[1]))
        cv2.circle(frame, prediction_px, 5, (255, 0, 0), -1) #BLUE
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

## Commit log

2022-12-04 Build support photos
    3d printed shell, and off the shelf GelBlaster product ready to be mashed up.
2022-12-04 Gelblaster Wingman Turret 3d printable files.
    Reality Ender S1 Pro example STL & .3mf files.
    [CE3S1_MAIN SHELL L Back.3mf, CE3S1_MAIN SHELL L Front.3mf, CE3S1_MAIN SHELL R Back.3mf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]
2022-12-04 mark all STL files as CCBYNCSA
    [CC_BYNCSA_L_Back.3mf, CC_BYNCSA_L_Back.stl, CC_BYNCSA_L_Front.3mf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]
2022-12-04 add dynamixel pic rail mount
    [CC_BYNCSA_Dynamixel_PicRail.stl]
2022-12-14 Fix bad PCB mount
    [CC_BYNCSA_Back_Errata_test_fix.stl, CC_BYNCSA_L_Back.stl, CC_BYNCSA_R_Back.stl]
2022-12-15 update 3mf files
    [CC_BYNCSA_L_Back.3mf, CC_BYNCSA_R_Back.3mf]
2023-03-25 Funding proposal for GelBlaster Wingman turret
    Formal request for a funding "match" to continue R&D efforts, and enabled / empower our team.
2023-07-18 barrel with luxonis Oak 1 mount
    [CC_BYNCSA_Luxonis_Barrel_01.stl]
2023-08-14 STEP files for Wingman Turret
    Orca Slicer pointed out that it has the ability to print from STEP files, and it will be higher resolution if you do so. So we've added them.
    [barrel.step, body L.step, body R.step]
2023-08-23 KF's Ender 5 s1 + k1 hotend mod & .5mm Deez nozzle
    My current documented settings for Ender 5 s1 with Polymaker PC6-CF alongside the modded K1 hot end, and Deez .5mm nozzle.
2023-09-14 Add turret base, move STEP & Slicer Configs to dedicated folders
    [3mm_to_5mm_wheel_bearing_spacer_centred.stl, Big_Tilt_Pulley_GT2-2.stl, CC_BYNCSA_Back_Errata_test_fix.stl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]
2023-09-17 cleanup old stl files
    [3mm_to_5mm_wheel_bearing_spacer_centred.stl, Big_Tilt_Pulley_GT2-2.stl, Gear_Side_Support.stl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]
2023-10-19 Add cherbini Turret v1
    [17tooth_small_pan_gear.stl, 25mm_gear_side_axle.stl, Idle_Side_Bearing_Mount.stl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]
2023-10-20 add SCAD script to make timing buckle
    [buckle.scad, buckle.stl]
2023-10-28 Joby mount for bottom of turret
    [JobyMount.scad, JobyMount.stl]
2023-11-03 add frame difference, and bounding boxes
2023-12-02 broken zeromq motion detect
    [motion_detection_client.py]
2024-01-21 Improved multi-threaded diff detector
2024-01-22 starting to pass bounding boxes from MT_diff to track.py NOT DONE YET
2024-05-04 Fixed video orientation and consistent frame rotation in the server.
2025-02-25 Create install.txt
    Add Jetson AGX Xavier install notes for latest compute
